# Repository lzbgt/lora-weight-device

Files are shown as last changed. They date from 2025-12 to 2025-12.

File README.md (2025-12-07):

# Hospital Urine Bag Monitoring System (LoRaWAN)

## Project Overview
A low-power, connected IoT device designed to automatically monitor urine output in hospital wards. It replaces manual visual checks with real-time digital logging, improving patient care and reducing nurse workload.

**Key Features:**
*   **Sensing:** Weight-based (Load Cell) for non-contact, universal bag compatibility.
*   **Connectivity:** **LoRaWAN** (Sub-1GHz) for deep indoor penetration and low infrastructure cost (1 gateway per ward).
*   **Battery Life:** Multi-year operation on AA batteries or Li-SoCl2.
*   **User Interface:** E-Ink Display for always-on visibility and local "Tare" button.
*   **Infrastructure:** Supports both **PoE** and **Wi-Fi** backhaul for the Gateway.

## Repository Structure

### Design Documents (`design_docs/`)
*   **`system_architecture.md`**: High-level topology, data flow, and server stack (ChirpStack).
*   **`hardware_design.md`**: Schematic concepts, chip selection (RAK3172, HX711), and detailed pin mapping.
*   **`mechanical_design.md`**: Enclosure styling, IP65 sealing, and the miniature load cell integration (Hook mechanism).
*   **`firmware_design.md`**: Software logic, state machine (Deep Sleep), and LoRaWAN payload format.
*   **`pcb_layout_guide.md`**: Critical routing rules for RF impedance and Analog noise reduction.
*   **`detailed_bom.md`**: Bill of Materials with part numbers and cost estimates.
*   **`solution_proposal.md`**: original proposal.

### Datasheets (`datasheets/`)
Contains reference specifications for critical components:
*   **RAK3172**: LoRaWAN Module.
*   **GDEY0213B74**: 2.13" E-Ink Display.
*   **HX711**: 24-Bit ADC.
*   **SSD1680**: Display Controller (Command Table).

## Getting Started

### 1. Hardware Development
*   Review `hardware_design.md` for the schematic connectivity.
*   Follow `pcb_layout_guide.md` for board layout, paying special attention to the **50Ω RF Trace** and **E-Ink Booster** loop.
*   Ensure the **Schottky Diode OR-ing** is implemented to protect the 3.3V rail.

### 2. Firmware Development
*   **Toolchain:** STM32CubeWL SDK + CMake + GCC ARM.
*   **Key Logic:** Implement the "Deep Sleep Loop" (Wait 400ms for HX711 -> Read -> Sleep).
*   **Display:** Use the SSD1680 driver with the specific bias voltages (+20V/-20V/+15V/-15V) defined in the hardware spec.

### 3. Mechanical Prototyping
*   Design the enclosure to fit the **Miniature Load Cell** (40mm).
*   Ensure the **Tube Retention Clip** is molded into the front shell to prevent measurement errors.

## License
Proprietary / Internal Company Use.

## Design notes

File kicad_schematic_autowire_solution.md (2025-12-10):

# KiCad schematic generation (no ERC) + “smart” auto‑wiring (obstacle‑avoiding)

This note assumes KiCad **6+** (`.kicad_sch` s‑expression format).

---

## 1) Generate schematics with *no ERC violations* (especially “unconnected pins”)

### 1.1 Treat ERC as a build step (don’t eyeball it)
Run ERC automatically after you generate/edit a schematic:

```bash
kicad-cli sch erc --format json --exit-code-violations path/to/root.kicad_sch
```

- `--exit-code-violations` lets you gate CI on a clean report.
- `--format json` makes it scriptable.  
(See KiCad CLI docs: https://docs.kicad.org/8.0/en/cli/cli.html)

You can also export a netlist for connectivity audits:

```bash
kicad-cli sch export netlist --format kicadsexpr path/to/root.kicad_sch
```

---

### 1.2 The three classic ERC pain points, and how to eliminate them

#### A) Pins that are intentionally unused → **add a no‑connect flag**
KiCad’s “no‑connection flags” explicitly tell ERC a pin is *intentionally* left open (and avoid “unconnected pin” violations).  
Docs explain the behavior and the stacked-pin corner case (no-connect breaks stacking connectivity):  
https://docs.kicad.org/6.0/en/eeschema/eeschema.html  
https://sources.debian.org/src/kicad/9.0.5%2Bdfsg-1~bpo13%2B1/doc/src/eeschema/eeschema_schematic_creation_and_editing.adoc

**File-format token:** the schematic file format defines:

```lisp
(no_connect (at X Y) (uuid <uuid>))
```

Source: KiCad developer file format docs: https://dev-docs.kicad.org/en/file-formats/sexpr-schematic/

**Script recipe**
1. Maintain an explicit “pin intent” list:
   - `CONNECTED` (must be in some net)
   - `NC` (must be intentionally unconnected)
2. For every `NC` pin, compute its absolute pin-end coordinate and emit a `no_connect` at that coordinate.
3. Re-run ERC; any remaining unconnected-pin issues are real mistakes.

> If a pin should *never* be connected in any schematic (true NC), set the **pin electrical type** to **Unconnected** in the *symbol library*. That also suppresses “unconnected pin” violations and prevents accidental wiring.

---

#### B) Power nets “not driven” → add **PWR_FLAG** (or a real power-output pin)
KiCad ERC often reports: **“Input Power pin not driven by any Output Power pins”** when power comes via connectors/batteries/etc. Add `PWR_FLAG` on those nets.

Docs:  
https://docs.kicad.org/6.0/en/eeschema/eeschema.html  
https://docs.kicad.org/8.0/en/getting_started_in_kicad/getting_started_in_kicad.pdf

**Script recipe**
- Identify nets with **power input** pins but **no power output** pins (via netlist export or ERC JSON).
- Place a `PWR_FLAG` symbol and wire it onto that net (or place the actual regulator output, etc.).

---

#### C) “It looks connected but ERC disagrees” → grid alignment & exact endpoints
KiCad connectivity is geometric: **wire endpoints must coincide** exactly with pin endpoints; wire crossings are not automatically connected.

Docs (grid + endpoint rule): https://docs.kicad.org/6.0/zh/eeschema/eeschema.html  
(“use a 50 mil grid”, and wires connect only when ends coincide)

**Script rule of thumb**
- Choose a grid (typically **50 mil = 1.27 mm**).
- Snap *every* generated coordinate to that grid.
- Ensure wires terminate **exactly** at pin ends (not “overlapping the symbol body”).

---

### 1.3 Minimal file-format snippets you’ll actually generate
Official s-expression format references:
- Schematic format: https://dev-docs.kicad.org/en/file-formats/sexpr-schematic/
- Common syntax (`pts`, `stroke`, units in **mm**): https://dev-docs.kicad.org/en/file-formats/sexpr-intro/index.html

**Wire**
```lisp
(wire
  (pts (xy X1 Y1) (xy X2 Y2) (xy X3 Y3))
  (stroke (width 0) (type default) (color 0 0 0 0))
  (uuid <uuid>)
)
```

**Junction** (use when you *intend* a connection at a 3+ segment intersection)
```lisp
(junction (at X Y) (diameter 0) (color 0 0 0 0) (uuid <uuid>))
```

**No-connect**
```lisp
(no_connect (at X Y) (uuid <uuid>))
```

---

## 2) Auto-wire pins “elegantly” (smart routing that avoids symbol bodies)

### 2.1 The big trick: separate *connectivity* from *ink*
In schematics, long wires are mostly UX debt. Net **labels** give correct connectivity without drawing a spaghetti bowl.

Docs: labels connect nets by name; you can connect without direct wire runs:  
https://docs.kicad.org/8.0/fr/eeschema/eeschema.html  (Labels section)

**Practical policy**
- **Local short connections** (inside a functional block): draw wires.
- **Global / long / high-fanout nets** (power, clocks, reset, buses, MCU GPIO groups): use *label stubs*.

That reduces the routing problem from “global autorouter” to “lots of tiny, clean stubs”.

---

### 2.2 Two-stage algorithm (what actually works in code)

#### Stage A — Placement (optional, but it’s where “smart” mostly lives)
No router can fully rescue bad placement. If you can, do a quick automatic placement pass:

- Build a graph: symbols = nodes, nets = hyperedges.
- Weight edges by:
  - number of pins on the net (fanout),
  - criticality (clock/reset), and/or
  - expected bus grouping (DATA[0..7]).
- Optimize a cost like:
  - total Manhattan distance of connected pins,
  - estimated crossings,
  - keep connectors on sheet edges, keep power at top/bottom, etc.

A force-directed layout or simulated annealing with grid snapping is usually “good enough”.

#### Stage B — Routing (orthogonal, obstacle-avoiding)
Model routing as grid-based Manhattan paths with obstacles.

**Geometry model**
- Coordinates: KiCad schematic s-expression uses **millimeters**.
- Use grid step: **1.27 mm** (50 mil) unless you have a reason not to.
- Obstacles:
  - symbol body bounding boxes (inflate by 1–2 grid steps as keepout),
  - optionally reference/value text boxes,
  - optionally existing wires as *soft* obstacles.

**Routing core**
- Use **A\*** on a 4-neighbor grid.
- Cost function (simple and effective):
  - `+1` per grid step (length)
  - `+BEND_PENALTY` when direction changes (minimize elbows)
  - `+CROSS_PENALTY` if you would cross an existing wire (prefer to detour)
  - `+NEAR_OBSTACLE_PENALTY` if too close to a symbol body (readability)
- Heuristic: Manhattan distance.

**Make it look human**
- After A\* returns a path (list of points), *compress* it:
  - remove collinear interior points so you emit 2–6 points, not 200.
- Use consistent posture:
  - default “horizontal then vertical” (or the reverse), and penalize “weird zigzags”.

---

### 2.3 Multi-pin nets: don’t route N² edges—build a trunk
For a net with many pins (e.g., `SPI_SCK` to 4 devices), you want a shared structure:

1. Compute a **hub** (Manhattan median):
   - `hub_x = median(pin_x)`, `hub_y = median(pin_y)`
2. Route each pin → hub (or pin → nearest point on a trunk line).
3. Merge overlapping segments.
4. Add junctions where branches meet.

This is a fast approximation to a rectilinear Steiner tree and works well visually.

**Even smarter heuristic**
- If pin points are mostly aligned horizontally, pick a **horizontal trunk** at `median(y)` and branch vertically.
- If mostly vertical, pick a vertical trunk.

---

### 2.4 Ultra-practical “elegant wiring” mode: stub + label
This is the cheat code for schematic legibility.

For each net:
- Place a label near each pin cluster.
- Draw a short orthogonal stub from pin end → label anchor.
- Don’t draw long inter-block wires at all.

You still get perfect connectivity and ERC cleanliness (as long as stub endpoints coincide with pin ends and label anchors are on the wire).

---

## 3) Skeleton Python approach (pseudo-code you can drop into a generator)

### 3.1 S-expression emitters (wire / junction / no_connect)
```python
from uuid import uuid4

def U(): return str(uuid4())

def sexpr_wire(points_mm):
    pts = " ".join(f"(xy {x:.3f} {y:.3f})" for x,y in points_mm)
    return f'(wire (pts {pts}) (stroke (width 0) (type default) (color 0 0 0 0)) (uuid {U()}))'

def sexpr_junction(x, y):
    return f'(junction (at {x:.3f} {y:.3f}) (diameter 0) (color 0 0 0 0) (uuid {U()}))'

def sexpr_no_connect(x, y):
    return f'(no_connect (at {x:.3f} {y:.3f}) (uuid {U()}))'
```

### 3.2 A* router (grid Manhattan, obstacle-avoiding) — minimal outline
```python
import heapq
from math import inf

DIRS = [(1,0),(-1,0),(0,1),(0,-1)]

def astar(start, goal, is_blocked, step=1):
    # start/goal are integer grid coords (gx, gy), not mm
    def h(a,b): return abs(a[0]-b[0]) + abs(a[1]-b[1])

    pq = [(h(start,goal), 0, start, None, None)]  # (f,g,node,parent,dir)
    best = {start: 0}
    parent = {}
    pdir = {}

    while pq:
        f,g,u,par,udir = heapq.heappop(pq)
        if u in parent:  # already expanded with best
            continue
        parent[u] = par
        pdir[u] = udir
        if u == goal:
            break

        for dx,dy in DIRS:
            v = (u[0]+dx, u[1]+dy)
            if is_blocked(v):
                continue
            bend = 0 if udir is None or udir==(dx,dy) else 5
            ng = g + 1 + bend
            if ng < best.get(v, inf):
                best[v] = ng
                heapq.heappush(pq, (ng + h(v,goal), ng, v, u, (dx,dy)))

    if goal not in parent:
        return None

    # reconstruct
    path = []
    cur = goal
    while cur is not None:
        path.append(cur)
        cur = parent[cur]
    path.reverse()
    return path
```

You’d wrap `is_blocked()` around:
- symbol keepouts,
- (optional) already-routed wires as soft blocks / high-cost regions,
- sheet boundaries.

Then convert grid coords → mm (`mm = grid * 1.27`) and compress collinear points.

---

## 4) A boring-but-realistic pipeline that works

1. Generate/update `.kicad_sch` (symbols + labels/wires).
2. Snap everything to grid; ensure wire endpoints coincide with pins.
3. Place `no_connect` on all intentionally unused pins.
4. Add `PWR_FLAG` where needed.
5. Run `kicad-cli sch erc --format json --exit-code-violations`.
6. Export SVG for visual diffing in CI (`kicad-cli sch export svg ...`).

When this passes reliably, you’ve basically built a schematic compiler.

---

## 5) Key references (official)
- Schematic file format (KiCad 6+): https://dev-docs.kicad.org/en/file-formats/sexpr-schematic/
- Common s-expression syntax (pts, stroke, **units in mm**): https://dev-docs.kicad.org/en/file-formats/sexpr-intro/index.html
- KiCad CLI (`kicad-cli sch erc`, netlist export): https://docs.kicad.org/8.0/en/cli/cli.html
- Eeschema docs (no-connect flag, PWR_FLAG, grid rules): https://docs.kicad.org/6.0/en/eeschema/eeschema.html

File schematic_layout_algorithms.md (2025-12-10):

# Schematic Auto-Layout Algorithms (KiCad `.kicad_sch` generator)

This document proposes **practical, implementable algorithms** to improve:
1) **Human readability (highest priority)**  
2) **Functional grouping / block coherence**  
3) **Space efficiency (only after 1 & 2 are satisfied)**  
4) **Automatic multi-page splitting (last resort)**

It is written to map cleanly onto your current Python-based KiCad schematic generator.

---

## 0) What the current generator does (and why it gets messy)

From `gen_urine_schematic.py`:

- **Placement**: instances are **hard-coded** in `INSTANCES = { ... (x,y) ... }` → no auto-placement.
- **Connectivity**: `emit_net()` draws **only a short stub from each pin and a net label** at the stub end.  
  There is **no actual multi-pin wiring / bus / junction topology**—the “connection” is purely by identical net labels.
- **Labeling**: label position is `at (stub_x, stub_y)` with a simple `justify` direction based on pin rotation.
  - There is **no collision detection** (label–label / label–symbol / label–wire).
  - High-fanout nets (GND/VCC/etc.) get **a label at every pin**, creating label density around dense ICs.

That combination is fast to generate, but it tends to produce **label clouds** near chips with many pins (MCU/module, large connectors), and it does not visually communicate circuit structure (only names).

---

## 1) Model the problem explicitly

Represent the schematic as **objects** with geometry and constraints:

### 1.1 Objects
- **Symbol instance** `S`: position `(x,y)`, orientation `rot`, bounding box `bbox(S)`
- **Pin** `p`: absolute anchor point `(x_p,y_p)`, preferred stub direction `dir(p)`
- **Net** `n`: a hyperedge connecting pins `P(n) = {p1, p2, ...}`
- **Wire segment** `w`: orthogonal polyline with clearance
- **Label** `L`: rectangle `bbox(L)` with anchor `(x_a,y_a)` and chosen candidate `(x,y,justify)`

### 1.2 Constraints (hard)
- No symbol overlap (bbox separation ≥ margin).
- Wires do not pass through symbols (treat symbol bbox inflated by clearance as obstacle).
- Label boxes do not overlap symbols; label–label overlaps should be minimized, ideally eliminated.
- Grid snapping.

### 1.3 Objectives (soft, prioritized)
1. **Readability**
   - minimize label overlaps, wire crossings, wire bends, “untraceable” hops
   - align and simplify (straight lines, consistent directions)
2. **Functional grouping**
   - strongly-related components should be near each other and visually “boxed”
3. **Space**
   - reduce page area only after readability/grouping are good enough
4. **Split to pages**
   - only if constraints cannot be met on one page

A key implementation detail: use a **lexicographic / tiered optimizer**:
- First minimize *readability cost*;
- subject to that, minimize *grouping cost*;
- subject to both, minimize *area*.

This prevents the “packed but unreadable” failure mode.

---

## 2) Recommended pipeline (works for small and large schematics)

1. **Preprocess nets**
   - Identify *global nets* (power/ground/high-fanout) and remove them from clustering.
2. **Functional grouping (clustering / partitioning)**
   - Assign components into blocks: Power, MCU, Sensors, Display, UI, Connectors, etc.
3. **Block-level placement (macro layout)**
   - Place block rectangles on page with a clear flow (left→right, top→bottom).
4. **Within-block placement (micro layout)**
   - Place the anchor IC/connector; attach passives around relevant pins; enforce conventions.
5. **Routing strategy**
   - Draw explicit wires for *local nets*; use labels/buses/harnesses for long or inter-block nets.
6. **Label placement (collision-aware)**
   - Choose label positions from candidates via greedy + local repair (or ILP if you want).
7. **Compaction (gentle whitespace reduction)**
   - Tighten only where it does not harm readability.
8. **If it still doesn’t fit → multi-page split**
   - Partition blocks into pages minimizing inter-page nets.

---

## 3) Step 1: Net preprocessing / classification

### 3.1 Detect nets that should NOT drive grouping
These nets connect almost everything and destroy clustering:
- `GND`, `VCC`, `VBUS`, `BAT`, `3V3`, `5V`, etc.
- Any net with degree ≥ `fanout_global` (e.g., ≥ 8 pins)

**Algorithm:**
```
global_nets = { n | degree(n) >= fanout_global } ∪ { n | name matches power_regex }
```

### 3.2 Net types drive drawing style
Classify nets into:
- **Global**: power rails, ground, high-fanout  
  → use *power symbols* or *one label per block*, not per-pin labels.
- **Local**: connects pins within same block and small degree (≤ 3)  
  → draw explicit wires (pattern routing).
- **Inter-block**: connects pins across blocks  
  → use ports + labels, or bus/harness if many nets cross between same two blocks.

---

## 4) Step 2: Functional grouping (block extraction)

### 4.1 Build a weighted component graph from the hypergraph
Construct a graph `G=(V,E)` where each component is a node. For each net `n` (excluding global nets):
- For all pairs of components `(u,v)` connected by `n`, add edge weight:
  - **Option A (simple):** `w += 1`
  - **Option B (better):** `w += 1/(degree(n)-1)`  
    (downweights medium-fanout nets so they don’t glue everything together)

Also add heuristics:
- Boost weights for “tight” relationships:
  - decoupling caps to IC VDD pins
  - crystal + load caps to MCU
  - regulator + inductor + diode + feedback resistors

You can infer these by net names (`VDD`, `VCC`, `FB`, `SW`, `XI/XO`) and component types.

### 4.2 Two practical clustering strategies

#### Strategy A: Anchor-based assignment (very practical)
1. Identify **anchors**: ICs/modules/connectors/regulators (high pin count or known library class).
2. Assign passives to nearest anchor by graph distance:
   - compute shortest-path distance in `G` from passive to each anchor
   - assign to the closest; tie-break by sum of incident edge weights

This produces blocks that match human intuition.

#### Strategy B: Community detection / partitioning (more general)
Run Louvain/Leiden (modularity) or spectral clustering on `G`.  
Then optionally label clusters by anchor types (power cluster, MCU cluster, etc.).

**Good hybrid**: Strategy A for passives + Strategy B to merge/split anchor clusters.

### 4.3 Block constraints you should enforce
- Minimum/maximum block size (component count) to avoid tiny or huge blocks.
- “Keep together” rules:
  - parts sharing a local analog reference should not be split
- “Separate” rules:
  - noisy power switching block should be spatially separated from sensitive analog block

---

## 5) Step 3: Block-level placement (macro layout)

### 5.1 Build the block graph
Nodes = blocks; edge weight = number of inter-block nets (excluding globals), or sum of net weights.

### 5.2 Place blocks with readable flow
A robust heuristic layout (works well for schematics):

1. Pick a **central block** (often MCU/module) as root.
2. Categorize blocks:
   - Power (sources/rails)
   - IO/connectors (edges)
   - Sensors/analog (near MCU but separated from switching power)
   - Display/UI (near MCU, usually right side)
3. Use a **constrained force model** on block rectangles:
   - attraction ∝ inter-block edge weight
   - repulsion to avoid overlap
   - soft constraints:
     - Power blocks prefer bottom-left / left
     - Connectors prefer page edges
     - UI/display prefer right/top-right
4. Snap block origins to grid.

This gives a good first macro layout.

### 5.3 Convert to a clean orthogonal macro arrangement (optional but recommended)
After force placement, apply **orthogonalization / rectilinear cleanup**:
- enforce a small set of canonical x-columns and y-rows for blocks
- align blocks to form clean “lanes” for buses

This increases readability more than it costs area.

---

## 6) Step 4: Within-block placement (micro layout)

### 6.1 Anchor-first placement
For each block:
1. Place the **anchor** (main IC/connector) at the block center.
2. Choose anchor **orientation** to minimize wire/label conflicts:
   - place high-traffic nets on left/right sides according to flow
   - keep power pins on top (if symbol supports that convention), ground bottom

Orientation selection can be done by minimizing:
```
rot_cost = Σ_n traffic(n) * projected_distance(pin_side(rot,n), preferred_side(n))
```

### 6.2 Attach passives near the pins they serve
For each passive `c` in block:
- Determine its **attachment pin(s)**:
  - For 2-pin passive: attach to the *more specific* net end (not GND/VCC)
  - For decoupling cap: attach to the IC VDD pin
- Compute target point = anchor pin position + outward offset.
- Place passives on a “ring” around anchor, grouped by side (left/right/top/bottom).
- Sort by the anchor pin y-order (for left/right sides) to reduce crossings.

This mimics how humans draw: passives line up alongside the pins they connect to.

### 6.3 Collision resolution (simple but effective)
After initial placement:
- Run a discrete “push-out” pass:
  - detect overlaps between symbol bboxes
  - for each overlap pair, move the lighter/smaller part outward along the nearest free direction
  - re-snap to grid
Repeat for a few iterations.

---

## 7) Step 5: Wiring strategy (make the topology legible)

### 7.1 Don’t label everything
Your current “stub+label for every pin” is the biggest readability killer.

Instead:
- **Global nets**: power symbols or one label per local rail, not per pin.
- **Local nets** (within a block): draw real wires (short, orthogonal).
- **Inter-block nets**: labels/ports; group many nets as buses.

### 7.2 Local-net orthogonal routing (pattern first, maze fallback)
For a connection between two pins A and B:

1. Try **I-route** (straight) if aligned and unobstructed.
2. Else try **L-route** (one bend) with two candidate elbows:
   - `(xA, yB)` and `(xB, yA)` if unobstructed.
3. Else try **Z-route** (two bends) using a small set of channel y-levels or x-levels.
4. Else run a lightweight **grid A*** router:
   - nodes on GRID
   - obstacles = inflated symbol bboxes + existing wires
   - cost = length + bend_penalty + near_wire_penalty

This keeps most wiring clean without heavy computation.

### 7.3 High-degree nets inside a block: use a local bus spine
If a net connects to many pins in the same block (but you don’t want global):
- create a **spine** (a horizontal or vertical trunk line)
- connect each pin to the spine with short orthogonal branches
- put **one net label** on the spine

This reduces label duplication dramatically and improves traceability.

---

## 8) Step 6: Label placement (collision-aware, practical)

Label placement is a classic “annotate anchors without collisions” problem.

### 8.1 Generate candidate label positions per anchor
For each label with anchor point `(x_a, y_a)` and a preferred direction `dir`:
- create candidates at increasing distance along `dir`: `d ∈ {0, 1, 2} * GRID`
- for each, create perpendicular nudges `p ∈ {-1, 0, +1} * GRID`
- include a “flip side” candidate if all else fails

For horizontal stubs, candidates are typically:
- right/left with above/below nudges

For vertical stubs:
- top/bottom with left/right nudges

### 8.2 Approximate text box size (good enough for collision tests)
If KiCad font size is `h` (e.g., 1.27mm), approximate:
- `char_w ≈ 0.6*h`
- `w = char_w * len(text)`
- `bbox = (x, y, x+w, y+h)` adjusted by justification

This is sufficient to avoid obvious overlaps.

### 8.3 Cost function (readability-first)
For each candidate `c` for label `i`:
```
cost(c) =
  W_overlap * (overlap_area_with_symbols + overlap_area_with_labels)
+ W_wire    * crossings_or_close_proximity_to_wires
+ W_dist    * distance(anchor, label)
+ W_edge    * outside_page_penalty
+ W_style   * (breaks_consistency_penalty)
```

Make `W_overlap` dominant.

### 8.4 Solver options

#### Option A (fast): Greedy + repair
1. Sort labels by congestion:
   - longer names first, then anchors in dense regions
2. Place each label at lowest cost candidate given already placed.
3. Repair pass: for remaining overlaps, push labels outward along least-colliding direction.

This handles 95% of cases.

#### Option B (strong): ILP for per-block label placement
Binary variable `x_{i,c}` = 1 if label i chooses candidate c.

Constraints:
- each label chooses exactly one candidate
- no overlap constraints for pairs that overlap (precompute conflict graph)

Objective:
- minimize Σ x_{i,c} * cost_{i,c}

This gives near-optimal label placement per block (typically small enough to solve quickly).

---

## 9) Step 7: Gentle compaction (space efficiency without hurting readability)

Once blocks, symbols, wires, labels are placed and collision-free:
- perform **compaction** to remove large unused gaps while preserving constraints.

### 9.1 Constraint-graph compaction (robust)
Build constraints:
- If object A must be left of B (because they overlap in y-range), add:
  `x_B ≥ x_A + width(A) + margin`
- Similar for vertical.

Solve by longest-path in a DAG (if you maintain a consistent ordering), or by iterative relaxation.

### 9.2 Heuristic “sweep” compaction (easy)
Repeat a few times:
- left-sweep: move each object left until it would violate any constraint
- top-sweep: move up similarly
- snap to grid

Stop when improvement is small.

Important: do compaction **after** label routing, otherwise you’ll reintroduce collisions.

---

## 10) Step 8: Multi-page splitting (last resort)

Only do this if:
- after grouping + placement + compaction, the layout cannot fit page bounds **without violating readability constraints**, or
- label density exceeds a threshold in one region even after rerouting.

### 10.1 Partition blocks into pages (min-cut with capacity)
Treat blocks as items with “area” (estimated block bbox) and “complexity” (component count, label count).  
Partition the block graph to minimize cut edges (inter-page nets), subject to:
- page area capacity
- max complexity per page

Practical algorithm:
- Start with one page; place largest/central block (MCU) first.
- Iteratively add neighboring blocks that:
  - fit capacity
  - add minimal new cut weight
- When no block fits, start a new page.
- Optionally run a KL/FM refinement pass to swap blocks between pages and reduce cuts.

### 10.2 Represent inter-page connectivity cleanly
- For a few nets: use **sheet ports** (hierarchical labels) or off-page connectors.
- For many nets between same two pages: create a **bus/harness**:
  - bus label like `EINK[CS,RST,DC,BUSY,SCK,MOSI]`
  - keep per-signal labels near endpoints, but route as a single bus trunk

### 10.3 Add a top-level overview page (recommended)
Generate a page 0:
- one block symbol per sheet
- buses between sheets
- power distribution

This massively improves human readability for multi-page designs.

---

## 11) How this maps back to your Python generator

### 11.1 Replace hard-coded `INSTANCES` positions
- Compute blocks and placements; assign `(x,y)` per instance from the algorithm.
- Keep your symbol parsing; add:
  - symbol bbox estimation
  - orientation (`rot`) selection support

### 11.2 Stop emitting one label per pin for global/high-degree nets
- Emit KiCad **power symbols** where possible.
- Or emit exactly one label per block spine and connect to it.

### 11.3 Add a label-placement module
- Maintain label objects; generate candidates; compute bbox overlaps; choose candidates.

### 11.4 Optional: generate actual wires for local nets
- Implement pattern routing; fallback to A* in a grid with obstacles.

---

## 12) Metrics & regression tests (so improvements are measurable)

Track:
- number of label–label overlaps (should be 0)
- number of label–symbol overlaps (must be 0)
- wire crossings (minimize)
- average pin-to-label distance (small)
- pages used (minimize *after* readability)
- block cut weight (minimize)

Create a golden-image regression:
- render PDF from KiCad and compare to baseline with perceptual diff (optional).

---

## 13) Practical defaults (good starting values)

- `GRID = 1.27mm`
- `fanout_global = 8`
- label candidate distances: `{0, 1, 2} * GRID`
- minimum symbol spacing: `2 * GRID`
- dominant label overlap weight: `W_overlap = 1000`
- wire bend penalty: `bend_penalty = 2*GRID` (in A* cost units)

---

### TL;DR
The biggest wins come from:
1) **Cluster into blocks** (ignore global nets for clustering)  
2) **Draw real wires inside blocks** and **use fewer labels** (spines/buses/global rails)  
3) **Collision-aware label placement** (candidates + greedy/ILP)  
4) **Only then** compact and split pages if truly necessary

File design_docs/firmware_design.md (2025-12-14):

# Firmware Design & Specification

## 1. Architecture: Professional SDK (CMake/STM32Cube)
The firmware will be developed as a standard C/C++ project using the **STM32CubeWL MCU Package** and built via **CMake**. This approach allows full control over the Sub-GHz radio stack, low-power modes, and memory layout.

### Toolchain & Environment
*   **Compiler:** `arm-none-eabi-gcc` (Latest stable).
*   **Build System:** **CMake** + **Ninja** / **Make**.
*   **SDK:** **STM32CubeWL Firmware Package** (HAL + LL Drivers).
*   **LoRaWAN Stack:** **LoRaMac-node** (Reference implementation from Semtech/ST) integrated within STM32Cube.
*   **IDE (Optional):** VS Code (with CMake Tools extension) or STM32CubeIDE (headless build support).

### Project Structure
```text
/firmware
├── CMakeLists.txt          # Main build script
├── Drivers/                # STM32 HAL/LL, CMSIS
├── Middlewares/            # LoRaWAN Stack, FreeRTOS (optional)
├── Core/
│   ├── Inc/                # Application Headers
│   └── Src/                # Application Source
│       ├── main.c          # Entry point & System Clock
│       ├── app_lorawan.c   # LoRaWAN Task/Callbacks
│       ├── hx711_driver.c  # Bit-banged or SPI-based driver
│       └── epd_driver.c    # SSD1680 E-Ink Driver
```

## 1.1 Development & Flashing Interface (USB‑C)
Hardware provides:
- **USB power** on `VBUS`
- **USB bridge MCU (STM32F042F6P6)** that exposes **USB CDC (UART2_TX/UART2_RX)** and **CMSIS‑DAP SWD** over the same cable.
- **Primary dev path:** single USB‑C into the on‑board STM32 bridge (3.3 V). SWD is wired to the target pogo pads and to the bridge so you can use either the on‑board CMSIS‑DAP or an external probe.

Recommended firmware/development flow:
- **Console:** enable `USART2` and route `printf`/logs to UART2.
- **Flashing:** use either (a) STM32 ROM bootloader over the USB CDC path (assert `BOOT0` + reset) or (b) SWD via the on‑board CMSIS‑DAP bridge.
  - `BOOT0=1` + reset → ROM bootloader on UART
  - `BOOT0=0` + reset → normal firmware

## 2. Operating Logic (State Machine)
To ensure <2uA sleep current, the application will use the **STM32 Low Power Manager (LPM)** utility or a custom `EnterStopMode` routine.

### Main Loop (Bare Metal or RTOS)
Given the simplicity, a **Super-Loop with Interrupts** or a light **FreeRTOS** implementation is suitable. The logic follows:

1.  **Bootloader:** Verify system integrity, jump to App.
2.  **System Init:**
    *   Clock: MSI Range 11 (48MHz) for active, LSE (32.768kHz) for RTC/LoRa.
    *   GPIO: Set all unused pins to Analog mode (High-Z) to save power.
    *   ADC: Calibrate VREFINT.
    *   Display: Init SPI, Clear screen (White), Show Logo, then Deep Sleep Display.
3.  **LoRaWAN Join:**
    *   Load Keys from Flash/EEPROM.
    *   Send Join Request (OTAA).
    *   Wait for Join Accept.
4.  **Deep Sleep Loop:**
    *   **RTC Alarm** wakes MCU every 60 seconds.
    *   **Wakeup Action:**
        *   Enable Power Gate (`PB5` LOW).
        *   **Wait 400ms** (HX711 Output Settling Time @ 10SPS, ref: **Datasheet Table 2, Note 1**).
        *   Read HX711 (Bit-bang `PB6`/`PA15` or Hardware SPI).
        *   Disable Power Gate (`PB5` HIGH).
        *   **CRITICAL:** Set `PB6` (SCK) Low/Analog.
        *   Measure Battery (ADC `PB4`).
    *   **Logic:**
        *   **Button Event (Interrupt):**
            *   **Short Press (< 2s):** Tare (Zero current weight).
            *   **Long Press (> 2s):** Toggle Measurement Mode (Standard 2000mL <-> Extended 8.5kg).
            *   *Note:* Extended range is hardware-limited to ~8.5kg due to HX711 Gain 32 saturation at 3.3V excitation.
        *   **Artifact Rejection:**
            *   Compare `Current_Weight` vs `Previous_Weight`.
            *   If delta > `MAX_FLOW_PER_MIN` (e.g., 50ml) AND not a "Reset/Empty" event:
            *   Ignore reading (assume tube pull/bed shake).
            *   Schedule rapid re-check (e.g., in 10 seconds).
        *   Delta check: Has weight changed > 50g (Stable)? -> Update Display.
        *   Alarm check: Weight > Threshold? -> Buzzer PWM (`PA8`) + Uplink.

## 4. Pseudocode (RUI3 Style)

```cpp
#include "RAK3172_RUI3.h"

// Settings
#define REPORT_INTERVAL (60 * 60 * 1000) // 1 hour
#define ALARM_THRESHOLD_ML 1800         // 80% of 2L bag

// Pin Definitions (Match Hardware Design)
#define PIN_POWER_GATE  PB5             // P-MOSFET (Low=ON, High=OFF)
#define PIN_BUZZER      PA8             // PWM
#define PIN_HX711_SCK   PB6
#define PIN_HX711_DT    PA15            // Data
#define PIN_EINK_BUSY   PA0             // Input
#define PIN_EINK_CS     PA4
#define PIN_EINK_DC     PA1
#define PIN_EINK_RST    PB12
#define PIN_BUTTON      PB3

// HX711 Config
// FX1901 Sensitivity = 20mV/V. Full Scale V_out = 66mV (at 3.3V).
// Gain 32 Range = +/- 51.5mV.
// Max Measurable Weight = (51.5 / 66) * 11kg = ~8.5kg.

// Global Flags
volatile bool evt_tare = false;
volatile bool evt_toggle_mode = false;
volatile uint32_t press_start_time = 0;

// Global Data
int32_t tare_offset = 0;
bool display_is_kg = false; // Default: mL (approx g)

void setup() {
    // ... Init code ...
    pinMode(PIN_BUTTON, INPUT_PULLUP);
    attachInterrupt(PIN_BUTTON, buttonPressHandler, FALLING);
    attachInterrupt(PIN_BUTTON, buttonReleaseHandler, RISING);
}

void buttonPressHandler() {
    press_start_time = millis();
}

void buttonReleaseHandler() {
    uint32_t duration = millis() - press_start_time;
    // Debounce: Ignore presses < 50ms
    if (duration > 50 && duration < 2000) {
        evt_tare = true;
    } else if (duration >= 2000) {
        evt_toggle_mode = true;
    }
}

void wakeUpHandler(void *data) {
    // 1. Power Up Sensor
    digitalWrite(PIN_POWER_GATE, LOW);
    // Wait 400ms (HX711 Output Settling Time @ 10SPS, ref: Datasheet Table 2, Note 1)
    delay(400); 
    
    // 2. Read Sensor (Channel B - Gain 32)
    // WARNING: FX1901 Full Scale (11kg) Output (66mV) > HX711 Range (51.5mV).
    // Sensor will SATURATE at > 8.5kg.
    int32_t raw_reading = readHX711_ChannelB();
    
    // 3. Power Down
    digitalWrite(PIN_POWER_GATE, HIGH);
    digitalWrite(PIN_HX711_SCK, LOW);

    // 4. Handle Input
    if (evt_tare) {
        tare_offset = raw_reading;
        evt_tare = false;
        // Refresh display to show 0
        updateDisplay(0, display_is_kg);
    }
    
    if (evt_toggle_mode) {
        display_is_kg = !display_is_kg;
        evt_toggle_mode = false;
        // Force update to show new unit icon
        float weight = (raw_reading - tare_offset) * CALIBRATION_FACTOR;
        updateDisplay(weight, display_is_kg);
    }

    // 5. Process Weight
    currentWeight = (raw_reading - tare_offset) * CALIBRATION_FACTOR;
    
    // ... Logic ...
}

void updateDisplay(float val, bool is_kg) {
    // Driver code to update E-Ink with value and "mL" or "kg" icon...
}
```

## 3. Key Driver Implementation Details

### A. E-Ink (SSD1680)
*   **Driver:** Port the GoodDisplay/Waveshare C routines to STM32 HAL SPI.
*   **Optimization:** Use **Partial Refresh** for volume updates (faster, less flickering) and **Full Refresh** only once every 6 hours to clear ghosting.
*   **Power:** Ensure the display is put into "Deep Sleep Mode" (command `0x10`, data `0x01`) before the MCU sleeps.

### B. HX711 (Load Cell)
*   **Config:** **Gain 32 (Channel B)**.
    *   **Gain Calculation:**
        *   **Sensor:** FX1901 (20mV/V). Excitation 3.3V. Full Scale Output = 66mV (at 11kg/25lb).
        *   **HX711 Range (Gain 32, 3.3V):** $\pm 0.5 \times (3.3V / 32) = \pm 51.5mV$.
        *   **Analysis:** The sensor's full 11kg output (66mV) technically exceeds the ADC range (51.5mV).
        *   **Application Reality:** Max urine bag weight is ~2kg (2000mL).
        *   **Operating Point:** At 2kg, signal is approx $66mV \times (2kg / 11kg) \approx 12mV$.
        *   **Conclusion:** Gain 32 provides **best resolution** for the primary 0-2kg target. Saturation at >8.5kg is a known trade-off.
        *   *Mitigation:* If >8.5kg measurement is required, firmware must switch to Gain 64 (Channel A) or hardware must reduce excitation voltage.
*   Since the RAK3172 is fast (48MHz), bit-banging the 24-bit readout requires delays to match the HX711 timing (max 400kHz SCK).
*   **GPIO Initialization:** All GPIO pins associated with the HX711 driver (SCK, DT) must be initialized using standard HAL enumerations (e.g., `GPIO_MODE_OUTPUT_PP`, `GPIO_NOPULL`) to ensure correct and robust pin configuration.
*   **Conversion:** `Weight_g = (Raw_Value - Tare_Offset) / Calibration_Factor`.

### C. LoRaWAN (LoRaMac-node)
*   **Region:** `LORAMAC_REGION_US915` or `LORAMAC_REGION_EU868` (defined in CMake).
*   **Class:** Class A.
*   **ADR:** Enabled (Adaptive Data Rate) to save power if close to gateway.

### D. Calibration Strategy (Dual-Slope)
To ensure maximum accuracy in the primary application range (0-2000mL) while supporting extended loads:
1.  **Zone 1 (0 - 2000g):** Calibrated with a 2kg master weight. This slope is optimized for the linear region of the sensor where urine volume matters most.
2.  **Zone 2 (2000g - 8500g):** A secondary correction factor is applied to handle potential non-linearity or droop in the sensor response at higher loads.

## 4. Payload Format (Packed)
*Same as previous design, consistent with CayenneLPP or Custom.*

| Byte | Function | Range / Value |
| :--- | :--- | :--- |
| **0** | Status Flags | Bit 0: Low Batt, Bit 1: Full Alarm, Bit 2: Blockage |
| **1** | Battery % | 0-100 (derived from V_measure vs V_full) |
| **2-3** | Volume (mL) | uint16_t (Little Endian) |
| **4-5** | Flow (mL/h) | uint16_t (Little Endian) |

## 5. CMakeLists.txt Snippet
```cmake
cmake_minimum_required(VERSION 3.16)
project(UrineMonitor C CXX)

set(CMAKE_C_STANDARD 11)
set(MCU_FLAGS "-mcpu=cortex-m4 -mthumb -mfpu=fpv4-sp-d16 -mfloat-abi=hard")

add_definitions(-DUSE_HAL_DRIVER -DSTM32WLE5xx)

# Include STM32CubeWL Sources
file(GLOB_RECURSE HAL_SOURCES "Drivers/STM32WLxx_HAL_Driver/Src/*.c")
file(GLOB_RECURSE LORA_SOURCES "Middlewares/Third_Party/LoRaWAN/LrMac/*.c")

add_executable(${PROJECT_NAME}.elf 
    Core/Src/main.c
    Core/Src/system_stm32wlxx.c
    ${HAL_SOURCES}
    ${LORA_SOURCES}
)

target_compile_options(${PROJECT_NAME}.elf PRIVATE ${MCU_FLAGS} -Wall -Os)
target_link_options(${PROJECT_NAME}.elf PRIVATE ${MCU_FLAGS} -T${CMAKE_SOURCE_DIR}/STM32WLE5CCUx_FLASH.ld -Wl,--gc-sections)
```

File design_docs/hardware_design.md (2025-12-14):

# Hardware Design (Current Plan)

This document is the *current* hardware plan used by the programmatic KiCad generators in `tools/`. It replaces earlier drafts that assumed a PCB‑mounted AA holder and large debug headers.

## Recent schematic/PCB updates
- **USB-C is now the single development connector**: full USB2 D+/D- feed an on‑board STM32F042 acting as USB CDC (UART) + CMSIS‑DAP SWD.
- **CH340C removed; STM32F042F6P6 replaces it** to provide both UART console and SWD/JTAG‑style debug over the same cable (3.3 V powered, with local decoupling).
- **Field power is via a 2‑wire JST‑PH** feeding the TPS61220 boost and Schottky OR-ing with the USB LDO.

## 1. System Role
- **Device:** LoRaWAN Class‑A end node
- **Connectivity:** Sub‑1 GHz LoRa (RAK3172 module)
- **UI:** 2.13" e‑paper (SSD1680) connected by FPC cable; local button + buzzer + status LED
- **Power:** USB‑C for development power; external battery pack for field deployment (2‑wire JST)

## 2. External Interfaces (Connectors)
- **USB‑C (Dev)**: single connector for development **power + console + flashing**
  - Power: `VBUS` (5 V) into an LDO → 3.3 V
  - Data: USB2 D+/D‑ into **STM32F042F6P6** (USB CDC + CMSIS‑DAP SWD)
  - Flashing: via STM32 UART bootloader over the USB CDC path (requires `BOOT0` + reset access; see `design_docs/firmware_design.md`)
  - SWD/JTAG: kept as **optional** pogo‑pad footprint (preferred) rather than a large 2.54 mm header
- **Battery (Field)**: 2‑wire JST‑PH (`BAT`, `GND`) to an external battery case/pack
- **Load Cell**: 4‑wire header (`E+`, `E-`, `A+`, `A-`) into HX711
- **Display**: 24‑pin 0.5 mm FPC connector for the GDEY0213B74 flex cable
- **Antenna**: u.FL/I‑PEX RF connector near the RAK3172 RF pin (short 50 Ω trace)

## 3. Key Silicon & Roles
### A. MCU + RF: RAK3172 (STM32WLE5)
- Integrated LoRa radio; certified module reduces RF risk.

### B. Load cell ADC: HX711 (SOIC‑16)
- 24‑bit ADC with PGA; reads strain gauge bridge.
- `HX_VCC` is **power‑gated** during sleep to eliminate bridge + HX711 draw.

### C. Power
- **Battery boost (field):** TI **TPS61220** (wide VIN, 3.3 V rail generation).
- **USB LDO (dev power):** Microchip **MIC5504‑3.3** from `VBUS` → 3.3 V.
- **Power ORing:** Schottky diodes into the system rail `VCC` (one from battery boost, one from USB LDO).
- **Battery sense:** 1 MΩ / 1 MΩ divider from `BAT` to ADC (`BAT_SENSE`) so firmware can report battery health even when on USB power.

### D. USB Console + Debug Bridge
- **STM32F042F6P6** provides USB CDC (console/logs, UART bootloader access) and CMSIS‑DAP SWD over the same USB‑C connector. Target SWDIO/SWCLK/NRST and UART2 RX/TX are wired to this bridge and also brought out to the pogo/debug header.

## 4. Pin Mapping (Summary)
### A. RAK3172 → System
| RAK3172 Pin | Net | Function | Notes |
|---:|---|---|---|
| 1 | `UART2_RX` | console RX | From USB bridge (STM32F042) TXD |
| 2 | `UART2_TX` | console TX | To USB bridge (STM32F042) RXD |
| 3 | `HX711_DT` | HX711 data | `PA15` |
| 4 | `HX711_SCK` | HX711 clock | `PB6` (must be LOW before gating) |
| 6 | `EINK_DC` | E‑ink D/C | `PA1` |
| 7 | `SWDIO` | SWD IO | optional pogo pads |
| 8 | `SWCLK` | SWD CLK | optional pogo pads |
| 9 | `I2C_SCL` | I2C | expansion |
| 10 | `I2C_SDA` | I2C | expansion |
| 13 | `EINK_MOSI` | SPI MOSI | `PA7` |
| 15 | `EINK_SCK` | SPI SCK | `PA5` |
| 16 | `EINK_CS` | SPI CS | `PA4` |
| 19 | `BUZZ_PWM` | buzzer PWM | `PA8` |
| 26 | `LED_STATUS` | status LED | `PB2` |
| 27 | `EINK_RST` | e‑ink reset | `PB12` |
| 29 | `EINK_BUSY` | e‑ink busy | `PA0` |
| 30 | `HX_GATE` | HX gate | drives SI2301 |
| 31 | `BAT_SENSE` | battery ADC | divider from `BAT` |
| 32 | `BTN_USER` | button | active‑low |

### B. STM32F042F6 (USB Bridge) → System
| STM32F042 Pin | Net | Function | Notes |
|---:|---|---|---|
| 16 / VDDA | `VCC` | 3.3 V | shared decoupling with C4 |
| 15 / VSSA | `GND` | ground | analog/digital common |
| 17 / PA11 | `USB_DM` | USB D– | to J3 |
| 18 / PA12 | `USB_DP` | USB D+ | to J3 |
| 19 / PA13 | `SWDIO` | target SWDIO | feeds RAK3172 / pogo |
| 20 / PA14 | `SWCLK` | target SWCLK | feeds RAK3172 / pogo |
| 14 / PB1  | `NRST`  | target reset | drives module reset |
| 8  / PA2  | `UART2_RX` | UART TX to RAK | bridge → target |
| 9  / PA3  | `UART2_TX` | UART RX from RAK | target → bridge |
| 4  / NRST | `NRST` | MCU reset | pulled up, brought to USB-C reset strap |

### C. Connectors (External)
| Ref | Pins | Nets | Purpose |
|---|---|---|---|
| J3 | USB‑C | `VBUS`, `USB_DP`, `USB_DM`, `CC1`, `CC2`, `GND` | Dev power + CDC + CMSIS‑DAP |
| J1 | 1x4 | `E+`, `E-`, `A+`, `A-` | Load cell |
| J2 | 24‑pin FPC | SPI + HV rails | E‑ink flex |
| J4 | 1x05 | `GND`, `VCC`, `I2C_SCL`, `I2C_SDA`, `BOOT0` | Minimal breakout |
| J5 | u.FL | RF feed | Antenna |
| BT1 | JST‑PH‑2 | `BAT`, `GND` | Battery input |

## 5. E‑Ink Display Notes (GDEY0213B74 / SSD1680)
- The PCB hosts only the **24‑pin FPC connector**; the display module mounts elsewhere in the enclosure and connects via the flex cable.
- SPI interface uses `BUSY/RES#/D/C#/CS#/SCL/SDA` and `BS1` strapped for 4‑wire SPI.
- The SSD1680 requires an **external booster/regulator application circuit** (inductor + MOSFET + Schottky diodes + capacitors) for the HV rails. Reference:
  - `datasheets/GDEY0213B74.pdf` (module reference circuit)
  - `datasheets/SSD1680.pdf` (Section 6.3 “Booster & Regulator”)
- Layout requirements (important):
  - Place the HV booster parts and HV capacitors **right next to the FPC connector**.
  - Keep the switching loop (L + MOSFET + diodes) **extremely small**.
  - Keep the HV area away from HX711 analog inputs and away from the RF feed.

## 6. PCB Placement Priorities (Professional Layout)
- **USB edge:** USB‑C centered on a short edge; STM32F042 bridge + LDO close to it; keep copper for heat spreading.
- **Analog corner:** Load cell connector + HX711 + its decoupling close together; keep noisy switching/HV away.
- **RF edge:** RAK3172 near top edge with u.FL near RF pin; short 50 Ω feed; ground stitching.
- **Display edge:** FPC connector on board edge to simplify cable routing; HV caps clustered next to pins.
- **Silkscreen:** keep `U* / R* / C* / J*` reference designators visible on `F.SilkS` (assembly‑friendly).

## 7. Known Issues / TODO
- Implement the SSD1680/GDEY0213B74 HV booster circuit in the schematic generator (currently some HV pins are stubbed as NC).
- Ensure `BAT_SENSE` measures the battery input (`BAT`) and not the post-OR system rail (`VCC`).

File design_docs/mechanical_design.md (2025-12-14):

# Mechanical & Enclosure Design

## 1. Design Requirements
*   **Environment:** Clinical Hospital Ward (Clean, but potential splashes).
*   **Rating:** **IP65** (Dust tight + Water jets). Essential for cleaning/disinfection.
*   **Mounting:** Must attach securely to standard Hospital Bed Rails (0.8" - 1.5" diameter) or hang from the bed frame.
*   **Load Interface:** Must securely hold a 2000mL (approx 2kg) urine bag.

## 2. Enclosure Concept (The "Shell")
*   **Material:** **ASA (Acrylonitrile Styrene Acrylate)** or **PC-ABS**.
    *   *Why:* UV stable (won't yellow under hospital lights), chemical resistant (alcohol/bleach wipes), high impact strength.
*   **Form Factor:** "Handheld" style vertical box with a hook at the bottom.
    *   *Dimensions (Approx):* 120mm (H) x 70mm (W) x 35mm (D).
*   **Assembly:** 2-part Snap-fit or Screw-together (4x M3 Stainless Steel screws from the back).
*   **Sealing:** Silicone O-ring groove around the perimeter of the mating surfaces.

## 3. Mounting Mechanism (Top)
The device needs to hang *from* the bed rail.
*   **Option A: Integrated Hook:**
    *   A large, robust hook molded into the back of the case.
    *   *Pros:* Cheap, no moving parts.
    *   *Cons:* Might not fit all rail shapes; can slide.
*   **Option B: Adjustable Clamp (Recommended):**
    *   A "C-clamp" style mechanism attached to the back.
    *   Rotatable knob to tighten onto the rail (0.8" - 1.5" range).
    *   Rubber pads inside the clamp to prevent slipping and scratching the bed rail.

## 4. Load Cell Integration (Ultra-Compact Button)
To achieve a minimal device footprint, we utilize a **Compression Load Button** (Coin-style sensor) instead of a large beam.

1.  **Sensor Selection:** **TE FX1901** or Generic **10-20mm Load Button** (Range: 10-20lb / 5-10kg).
    *   *Size:* ~15mm Diameter.
    *   *Type:* Compression Force Sensor.
2.  **Mechanical Interface ("Pull-to-Push"):**
    *   **Shelf:** The sensor sits on a structural PCB or plastic shelf inside the case, facing **UP**.
    *   **Hook Shaft:** Passes *through* a hole next to (or under) the sensor assembly.
    *   **Bridge/Yoke:** The top of the hook connects to a rigid "Bridge" piece that spans over the sensor.
    *   **Action:** When the bag pulls the hook **DOWN**, the Bridge presses **DOWN** onto the sensor's "button" surface.
3.  **Sealing:**
    *   Standard O-ring or Rubber Boot where the hook shaft exits the bottom shell.
4.  **Overload Protection:**
    *   **Hard Stop:** The Bridge hits the PCB/Shelf supports after 0.5mm of travel, preventing sensor crushing during gross overload.

## 5. Tube Management (Strain Relief) - Critical
*   **Problem:** Tension on the catheter tube (from patient movement) creates variable lift/force on the bag, corrupting weight data.
*   **Solution:** Integrated **Tube Retention Clip** molded into the **Stationary Front Shell**.
*   **Usage:** 
    1.  The nurse clips the incoming catheter tube into this holder.
    2.  This absorbs all pulling forces into the device body (and bed rail).
    3.  A consistent "slack loop" of tubing hangs between the Clip and the Bag Inlet, ensuring only the bag's weight is measured.

## 6. RF & Antenna Placement
*   **Location:** The antenna (Flex PCB type) must be adhered to the **Top Front** of the inside of the plastic shell.
*   **Separation:** Keep the antenna at least **20mm away** from the metal Bed Rail Clamp mechanism (Back) and the Load Cell/Hook assembly (Bottom).
*   **Orientation:** Vertical polarization is preferred for best omnidirectional coverage in a single-story ward.

## 7. User Interface & Battery
*   **Display:** E‑Ink (GDEY0213B74) mounted behind a clear PC (Polycarbonate) window glued into the Front Shell. The window should have a black masked border to hide the glue line.
*   **Buttons:** **Membrane Keypad** (Stick-on) on the front surface.
    *   *Routing:* The FPC tail from the keypad must pass through a sealed slot (potted with resin) to reach the PCB.
    *   *Functions:* "Tare/Zero" (Short Press), "Range Toggle" (Long Press).
*   **Battery (Current Plan):**
    *   The battery pack is in a **separate battery case** and connects to the PCB via a **2‑wire JST‑PH cable**.
    *   *Why:* reduces PCB size, reduces mechanical constraints on the PCB, and allows battery service without opening the electronics compartment.
*   **USB‑C (Development):**
    *   USB‑C should be accessible for bench power + console + flashing (via UART bootloader).
    *   For IP‑rating, consider a gasketed rubber plug or a recessed port with a sealing cap.

## 7. 3D Printing for Prototype
*   **Process:** FDM or SLA.
*   **Material:** PETG (easy to print, durable) or Resin (SLA for smooth finish).
*   **Draft Angle:** If moving to injection molding later, ensure vertical walls have 1-2 degrees of draft.

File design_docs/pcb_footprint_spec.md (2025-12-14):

# PCB Physical Specification (Current Plan)

This spec replaces earlier drafts that assumed a PCB‑mounted AA holder. In the current plan:
- The **battery is off‑board** (separate battery case) and connects via a **2‑wire JST‑PH** cable.
- The **display is off‑board** (mounted in the enclosure front) and connects via a **24‑pin FPC** cable.

## 1. Board Outline (Target)
- **Goal:** make the PCB as small as practical while keeping routing sane and respecting RF/HV keepouts.
- **Current generator default:** 60mm (W) × 80mm (H) rectangle (USB‑C centered on the bottom short edge, STM32F042 debug bridge + LDO/Schottky just above it, JST‑PH battery at the lower‑left, load cell on the left edge, FPC on the right edge, u.FL near the top edge).
- **Target after tightening:** shrink to the minimal envelope around connectors + functional blocks.

## 2. Edge Anchors (Must‑Haves)
- **USB‑C:** centered on one short edge (development power + console + flashing via UART bootloader).
- **FPC (Display):** placed on an edge so the cable exits cleanly to the display.
- **Battery JST:** currently on the bottom edge offset from USB to reduce crowding; keep clearance for harness strain relief.
- **u.FL:** on the top edge near RAK3172 RF pin (short 50 Ω feed).
- **Load cell header:** edge accessible for harness / strain relief.

## 3. Keepouts / Constraints
- **RF:** keep the RAK3172 RF feed short; use ground stitching; avoid copper “slots” under the feed.
- **E‑paper HV:** booster loop and HV caps stay close to the FPC pins; keep noisy HV away from HX711 analog inputs.
- **Thermal:** USB power entry (LDO + ORing diode) is a heat source; keep it away from HX711 and from the RF feed, and give it copper to spread heat.

## 4. Silkscreen / Assembly
- Reference designators (`U*`, `R*`, `C*`, `J*`) must be visible on `F.SilkS` and placed clear of pads so assembly/debug is possible without the 3D viewer.

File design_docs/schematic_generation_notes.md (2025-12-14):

# Programmatic Schematic Generation Notes

This repo generates the KiCad schematic *from code* (`tools/gen_urine_schematic.py`) to keep the design reproducible and reviewable.

## Current design intent (high level)
- **Dev interface:** USB‑C + STM32F042 bridge (power + USB‑UART console + CMSIS‑DAP SWD + UART bootloader flashing)
- **Field power:** external battery pack via 2‑wire JST‑PH
- **Display:** off‑board e‑paper connected via 24‑pin FPC cable (PCB only hosts the connector + required HV booster parts)
- **RF:** u.FL connector and short 50 Ω feed from RAK3172

## Generator conventions
- Snap all placements to a 1.27 mm grid.
- Use per‑pin stubs + global labels (readable PDFs; minimizes accidental wire merges).
- Add `PWR_FLAG` on driven rails to keep ERC clean.
- Add explicit `no_connect` markers for unused pins.
- Keep reference/value/footprint text away from pins so exported PDFs are readable.

## How to regenerate everything (headless)
Use the single entrypoint script:
```bash
bash tools/regen_kicad_project.sh
```
This regenerates the schematic, runs ERC, generates/places/routs the PCB, runs DRC, exports PDFs/PNGs, and produces JLCPCB fabrication artifacts.

## Notes
- If ERC shows merged nets, it is usually caused by overlapping stub endpoints; nudging the responsible instance a few grid steps fixes it.
- Keep the schematic “blocky”: USB/Power, RF, HX711 analog, and Display/HV should each read as a separate cluster even in a single‑page sheet.
- USB-C is wired with full D+/D- pins into the STM32F042 bridge (powered from the 3.3 V rail with CC pulldowns) so a single cable provides development power + UART (CDC) + CMSIS‑DAP SWD.

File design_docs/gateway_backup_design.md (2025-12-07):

# Backup Gateway Design (Plan B)

> **⚠️ WARNING: UNVERIFIED DESIGN**
> This design proposal (Plan B) lacks validating datasheets for the core components (**ESP32-S3** and **RAK5146**) in the project repository. It serves as a conceptual backup only. The primary, validated solution is the **RAK7268V2 Commercial Gateway** (see `system_architecture.md` and `datasheets/rak7268v2_datasheet.md`). Implementation of this custom gateway should not proceed without full component validation.

## 1. Objective
To provide a proprietary, cost-effective custom gateway design as a backup to the commercial RAK7268V2. This design focuses on component availability and stripped-down functionality (LoRaWAN Packet Forwarder only).

## 2. Architecture
A **"Hybrid-Gateway"** architecture: High-performance ESP32-S3 drives a standard LoRaWAN Concentrator.

*   **Host Processor:** **Espressif ESP32-S3-WROOM-1-N8R2** (8MB Flash, 2MB PSRAM).
    *   *Interfaces:* SPI (LoRa), SPI/RMII (Ethernet), USB (Debug/Power).
*   **LoRa Concentrator:** **RAK5146** (SPI Version, SX1303).
    *   *Connector:* Standard Mini-PCIe.
*   **Ethernet:** **WIZnet W5500** (SPI) or **LAN8720** (RMII). *Selection: W5500 for simpler SPI routing.*

## 3. Power Design (Critical)
The SX1303 Concentrator bursts up to **500mA**. A standard LDO is insufficient.
*   **Input:** USB-C (5V).
*   **Regulation:** **Buck Converter** (Step-Down) to 3.3V.
    *   **Chip:** **MPS MP2359** (1.2A High Efficiency).
    *   **Inductor:** 4.7uH Shielded Power Inductor.
    *   **Capacitors:** 22uF Ceramic on Input and Output.

## 4. Pin Mapping (ESP32-S3)

| ESP32 Pin | Function | Connection |
| :--- | :--- | :--- |
| **GPIO 1** | SPI_MOSI | **RAK5146 MOSI** & **W5500 MOSI** |
| **GPIO 2** | SPI_MISO | **RAK5146 MISO** & **W5500 MISO** |
| **GPIO 3** | SPI_CLK | **RAK5146 SCLK** & **W5500 SCLK** |
| **GPIO 4** | GPIO | **RAK5146 CS#** (Chip Select) |
| **GPIO 5** | GPIO | **W5500 CS#** (Chip Select) |
| **GPIO 6** | GPIO | **RAK5146 RST** (Reset) |
| **GPIO 7** | GPIO | **W5500 RST** (Reset) |
| **GPIO 8** | GPIO | **W5500 INT** (Interrupt) |
| **GPIO 9** | GPIO | **Status LED** (Green) |
| **GPIO 10** | GPIO | **Error LED** (Red) |
| **USB D+/D-** | USB | **USB-C Connector** (Programming) |

## 5. Mini-PCIe Slot Pinout (RAK5146 Target)
*   **Pin 2 (3.3V):** Connect to MP2359 Output.
*   **Pin 24 (3.3V):** Connect to MP2359 Output.
*   **Pin 52 (3.3V):** Connect to MP2359 Output.
*   **Pin 4, 9, 15, 18, 21... (GND):** Connect to GND Plane.
*   **Pin 19 (SPI_MOSI):** Connect to ESP32 GPIO 1.
*   **Pin 21 (SPI_MISO):** Connect to ESP32 GPIO 2.
*   **Pin 23 (SPI_SCK):** Connect to ESP32 GPIO 3.
*   **Pin 25 (SPI_CS):** Connect to ESP32 GPIO 4.
*   **Pin 17 (RST):** Connect to ESP32 GPIO 6.

## 6. Detailed Bill of Materials (BOM)

| Item | Manufacturer | Part Number | Description | Qty | Unit Cost |
| :--- | :--- | :--- | :--- | :--- | :--- |
| **Host MCU** | Espressif | **ESP32-S3-WROOM-1-N8R2** | Wi-Fi/BLE Module, 8MB/2MB | 1 | $2.80 |
| **Concentrator** | RAKwireless | **RAK5146 (SPI)** | SX1303 LoRaWAN Card | 1 | $45.00 |
| **Ethernet Chip** | WIZnet | **W5500** | SPI to Ethernet Controller | 1 | $1.50 |
| **Ethernet Jack** | Pulse | **J0011D21BNL** | RJ45 with Magnetics | 1 | $1.20 |
| **Buck Converter** | MPS | **MP2359** | 1.2A 3.3V Step-Down | 1 | $0.40 |
| **Inductor** | Generic | **CDRH4D28-4R7** | 4.7uH Power Inductor | 1 | $0.15 |
| **PCIe Socket** | Generic | **AS0B221-S68Q-7H** | 52-Pin Mini-PCIe H=4mm | 1 | $1.00 |
| **USB Connector** | Generic | **Type-C 16-Pin** | Power + Data | 1 | $0.40 |
| **PCB** | JLCPCB | **Custom** | 2-Layer, Thermal Vias | 1 | $3.00 |
| **Enclosure** | Generic | **100x100 ABS** | Waterproof Box | 1 | $5.00 |
| **TOTAL** | | | | | **~$60.45** |

## 7. Layout Guidelines
1.  **Thermal Management:** The MP2359 and RAK5146 generate heat. Place large copper pours on Top and Bottom layers connected by multiple vias under the Mini-PCIe latch area and power regulators.
2.  **Ethernet:** Keep differential pairs (TX+/TX-, RX+/RX-) from the W5500 to the RJ45 jack short and length-matched.
3.  **RF:** The RF is handled on the RAK5146 card, so the baseboard only deals with digital signals. Keep SPI lines direct.

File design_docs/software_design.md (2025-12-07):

# Software & Backend Design

## 1. High-Level Architecture
The software backend transforms raw LoRaWAN packets into actionable medical insights. It is designed to be **containerized (Docker)** for easy on-premise hospital deployment.

```mermaid
graph LR
    A[Gateways] -->|UDP/Semtech Packet Forwarder| B(ChirpStack Network Server)
    B -->|MQTT Publish| C[Python App Controller]
    C -->|Write| D[(PostgreSQL TimescaleDB)]
    C -->|Websocket| E[React Dashboard]
    C -->|HL7v2 / FHIR| F[Hospital EMR System]
```

## 2. Components

### A. LoRaWAN Network Server (LNS)
*   **Choice:** **ChirpStack** (Open Source).
*   **Role:** Manages gateways, authenticates devices (Join Request), decrypts payloads, handles downlink queue.
*   **Integration:** Publishes decrypted events to MQTT topic `application/ID/device/EUI/event/up`.

### B. Application Controller (The "Brain")
*   **Language:** Python (FastAPI or Django) or Node.js.
*   **Functions:**
    *   **MQTT Client:** Subscribes to ChirpStack data.
    *   **Payload Decoder:** Unpacks the 6-byte binary payload into JSON (e.g., `{"volume": 1200, "flow": 50, "alarm": false}`).
    *   **Logic Engine:** 
        *   *Alerts:* If `volume > 1800` -> Send Notification.
        *   *Analytics:* Calculate shift totals (7am-7pm).
    *   **API:** REST API for the frontend to fetch bed status.

### C. Database
*   **Primary:** **PostgreSQL** with **TimescaleDB** extension.
*   **Why:** Medical data is time-series. We need efficient storage of volume readings every hour/minute for history graphs.
*   **Schema Example:**
    ```sql
    TABLE measurements (
        time        TIMESTAMPTZ NOT NULL,
        device_eui  VARCHAR(16),
        patient_id  VARCHAR(50),
        volume_ml   INT,
        flow_rate   INT,
        battery_pct INT
    );
    ```

### D. Frontend Dashboard
*   **Framework:** **React.js** or **Vue.js**.
*   **Views:**
    *   **Ward Map:** Grid view of beds with color codes (Green=OK, Red=Full/Blocked, Yellow=Low Battery).
    *   **Patient Detail:** Line graph of urine output over the last 24h.
    *   **Settings:** "Tare" button (sends LoRaWAN downlink to device), Alarm thresholds.

## 3. Integration with Hospital Systems (EMR)
Hospitals use legacy systems. We need an **Integration Engine**.
*   **Protocol:** **HL7 v2.x** (Most common) or **FHIR** (Modern).
*   **Workflow:**
    1.  Nurse scans Patient Wristband + Device QR code.
    2.  App Server links `Device_A` to `Patient_123`.
    3.  Every hour, App Server generates an **ORU^R01** (Observation Result) HL7 message.
    4.  Sends to Hospital Interface Engine (Mirth Connect / Iguana).

## 4. Deployment Stack (Docker Compose)
```yaml
version: '3'
services:
  chirpstack:
    image: chirpstack/chirpstack:4
    ports: ["8080:8080"]
  
  postgres:
    image: timescale/timescaledb:latest-pg14
    
  app-server:
    build: ./backend
    command: python main.py
    
  frontend:
    build: ./frontend
    ports: ["3000:80"]
```

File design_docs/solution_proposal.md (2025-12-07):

# Hospital Urine Drainage Bag Monitoring System - Solution Proposal

## 1. Executive Summary
This document proposes an optimized solution for the "Intelligent Monitoring Device for Hospital Urine Drainage Bag Volume". The original proposal (BLE + Wi-Fi Gateway) faces challenges regarding signal interference, gateway density, and battery maintenance in a high-density hospital environment. 

**Key Improvements:**
*   **Connectivity:** Switch from **BLE** to **Sub-1GHz (LoRaWAN or Proprietary 915/868 MHz)**.
*   **Infrastructure:** Reduce gateway count from "one per room" to "one per ward/floor".
*   **Sensing:** Stick with **Load Cell (Weight)** for compatibility but implement **Capacitive Sensing** for a next-gen "smart sticker" variant.

## 2. Comparison: Current vs. Proposed

| Feature | Current Idea (BLE + Wi-Fi) | Proposed Solution (Sub-1GHz + Load Cell) |
| :--- | :--- | :--- |
| **Frequency** | 2.4 GHz | Sub-1GHz (e.g., 868/915 MHz) |
| **Interference** | **High** (Wi-Fi, Zigbee, Medical Equip.) | **Low** (Separate from critical Wi-Fi) |
| **Range** | Short (~10-30m) | Long (Hundreds of meters indoor) |
| **Gateway Count** | High (1 per room recommended) | **Low** (1 per ward/floor can handle 1000+ nodes) |
| **Battery Life** | Moderate | **Extended** (Lower transmission power for range) |
| **Cost** | High infra cost (many gateways) | **Lower infra cost** (fewer gateways) |

## 3. Detailed Technical Architecture

### A. Bedside Monitoring Unit (The "Node")
*   **Sensor:** 
    *   *Primary:* **Strain Gauge (Load Cell)**. Robust, works with any standard bag.
    *   *Optimization:* Design the enclosure to clip onto standard bed rails with a retractable hook to minimize profile.
    *   *Alternative:* **Capacitive Level Strip**. A disposable or reusable adhesive strip. Benefits: No mechanical parts, extremely low profile. Drawbacks: Specific to bag geometry.
*   **Microcontroller:** Ultra-low power MCU (e.g., STM32L4 series or TI CC13xx).
*   **Radio:** Sub-1GHz Transceiver (LoRa or FSK). 
    *   *Why:* Penetrates walls easily; avoids the crowded 2.4GHz spectrum used by hospital Wi-Fi and monitoring equipment.
*   **Power:** Li-ion rechargeable or Replaceable AA batteries (2+ years life).
*   **User Interface:** E-Ink Display (Low power, high visibility) or simple LED indicators.

### B. The Gateway (The "Hub")
*   **Radio:** Sub-1GHz Concentrator (8-channel LoRaWAN or Proprietary).
*   **Uplink:** Wi-Fi / Ethernet (PoE preferred for reliability) / Cellular (LTE-M as backup).
*   **Capacity Analysis (High Density Scenario):** 
    *   *Scenario A (Standard):* 100 beds, reporting every **1 hour**.
        *   Load: 100 packets/hour.
        *   Utilization: < 0.2% of gateway capacity.
    *   *Scenario B (Stress Test - Client Request):* 100 beds, reporting every **10 minutes**.
        *   Traffic Load: 100 devices × 6 packets/hour = **600 packets/hour** (10 packets/minute).
        *   *Capability:* A standard 8-channel gateway handles ~60,000+ packets/hour.
        *   *Conclusion:* Even at 10-minute intervals, the network load is **~1%** of the gateway's maximum. The system is "bored" and can easily scale further or handle frequent alarm spikes.

## 4. Functional Workflow
1.  **Measurement:** Device wakes up every minute to sample weight.
2.  **Filtering:** Algorithms filter out "bed shaking" or "patient movement" artifacts.
3.  **Reporting:** 
    *   *Routine:* Transmits volume data once per hour.
    *   *Alarm:* Transmits **immediately** if:
        *   Volume > Threshold (e.g., 80% full).
        *   No flow detected for X hours (potential blockage).
        *   Sudden weight drop (leak/emptied).
4.  **Server:** Central dashboard shows status of all beds in the ward.
5.  **Integration:** HL7/FHIR interface to push data to the Hospital Information System (HIS).

## 5. Cost Analysis (Per 25-Bed Ward)

A direct cost comparison between the two architectures reveals significant savings with the Sub-1GHz approach, primarily driven by infrastructure reduction.

| Item | Option A: BLE + Wi-Fi (Original) | Option B: Sub-1GHz (Proposed) | Notes |
| :--- | :--- | :--- | :--- |
| **Node Hardware** | ~$15.00 / unit | ~$7.00 / unit | *STM32WLE5 SoC reduces BOM cost vs discrete BLE+MCU modules.* |
| **Node Total (25 beds)** | $375.00 | $175.00 | |
| **Gateway Unit Cost** | ~$30.00 (Simple Bridge) | ~$200.00 (Commercial Indoor) | *LoRa gateway is more expensive per unit, but...* |
| **Gateway Quantity** | 25 (1 per room) | 1 (1 per ward) | *...you only need ONE.* |
| **Gateway Total** | **$750.00** | **$200.00** | |
| **Installation (Labor)** | High (25 power outlets, 25 setups) | Low (1 central setup) | *Estimated 10x labor savings.* |
| **Total Hardware Cost** | **~$1,125.00** | **~$375.00** | **~66% Hardware Savings** |

### Economic Conclusion
The **Sub-1GHz solution is ~3x cheaper** in initial hardware capability. 
*   **Infrastructure Savings:** $550 per ward.
*   **Device Savings:** $200 per ward.
*   **Hidden Savings:** drastically reduced IT management (25 IP addresses vs 1 IP address per ward).

## 6. Why this is better
1.  **Reliability:** Sub-1GHz is far less likely to drop connections in a hospital filled with Wi-Fi signals.
2.  **Maintenance:** Fewer gateways mean fewer points of failure and less IT management overhead.
3.  **Scalability:** Easier to deploy. Just plug in one gateway at the nurses' station and deploy nodes in rooms.

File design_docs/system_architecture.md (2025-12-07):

# System Architecture Design
## Intelligent Hospital Urine Bag Monitoring System

### 1. High-Level Topology
The system follows a **Star-of-Stars** topology typical of LoRaWAN networks. It is designed for high density, deep indoor penetration, and low power consumption.

```mermaid
graph TD
    subgraph "Patient Room (The Node)"
        A[Urine Bag] -->|Weight| B(Smart Monitor Device)
        B -->|Sub-1GHz RF| C
    end

    subgraph "Ward Level (The Infrastructure)"
        C[LoRaWAN Gateway] -->|Ethernet/PoE| D[Hospital Network Switch]
    end

    subgraph "Server Room / Cloud (The Backend)"
        D --> E[Network Server LNS]
        E -->|MQTT| F[Application Server]
        F --> G[Database]
        F --> H[Hospital Information System HIS]
    end

    subgraph "Nurses Station"
        F --> I[Dashboard / Tablet]
        F --> J[Alert System Pager/Light]
    end
```

### 2. Data Flow Architecture

1.  **Sensing Layer (Edge):**
    *   **Input:** Physical weight of urine bag.
    *   **Processing:** ADC conversion (HX711), artifact filtering (removing motion noise), formatting payload.
    *   **Output:** Encrypted LoRaWAN packet (Payload: `Volume_mL`, `Battery_%`, `Status_Flags`).

2.  **Transport Layer:**
    *   **Protocol:** LoRaWAN 1.0.3 or 1.1 (Class A devices).
    *   **Frequency:** Region specific (e.g., US915, EU868).
    *   **Gateway Connectivity Models (Select based on Hospital Infrastructure):**
        *   **Option 1: PoE Line (Preferred):**
            *   **Data:** Ethernet.
            *   **Power:** 802.3af/at PoE from Switch or Injector.
            *   **Pros:** Single cable, high reliability, no separate power supply needed.
        *   **Option 2: Wi-Fi Line:**
            *   **Data:** Wi-Fi (WPA2/WPA3 Enterprise).
            *   **Power:** 12V DC Adapter or USB-C.
            *   **Pros:** Flexible placement where Ethernet drops are missing.
    *   **Gateway Hardware:** **RAK7268V2** (Supports both Ethernet/PoE and Wi-Fi/DC out of the box).

3.  **Network Layer (LNS):**
    *   **Software:** ChirpStack (Self-hosted for privacy) or The Things Stack Enterprise.
    *   **Functions:** Deduplication (if multiple gateways hear a node), Authentication (OTAA), Decryption (AppSKey), Data forwarding via MQTT/Webhooks.

4.  **Application Layer:**
    *   **Business Logic:**
        *   Decodes binary payload.
        *   Calculates urine flow rate (mL/hour).
        *   Checks thresholds (Full > 80%, Flow < 10mL/h for 2 hours).
        *   Manages patient-to-device mapping.
    *   **Storage:** Time-series database (InfluxDB) for sensor data; Relational DB (PostgreSQL) for patient/device management.

### 3. Security Architecture
Given the medical context (HIPAA/GDPR considerations), security is paramount, even though the raw data (weight) is not PII until associated with a patient record.

*   **Device Level:** 
    *   **AES-128 Encryption:** Native to LoRaWAN (NwkSKey for network, AppSKey for payload).
    *   **Hardened Firmware:** Read-out protection enabled on STM32 to prevent cloning.
*   **Key Management & Provisioning:**
    *   **OTAA (Over-the-Air Activation):** Devices are provisioned with a unique `DevEUI`, `JoinEUI` (AppEUI), and `AppKey` at the factory.
    *   **Ownership:** The Hospital IT department (or the Service Provider) owns the **Join Server**. Keys are not shared with third-party network operators if using a private ChirpStack instance.
    *   **Lifecycle:** Keys are rotated only upon device reset/re-join. Compromised devices can be blacklisted by `DevEUI` in the LNS.
*   **Network Level:**
    *   **Private Deployment:** Gateways point to a local IP, keeping data within the hospital intranet.
    *   **TLS/SSL:** All traffic from Gateway to Server and Server to UI is encrypted.
*   **Application Level:**
    *   **Role-Based Access Control (RBAC):** Nurses view ward status; Admins manage devices.
    *   **Audit Logs:** Track who acknowledged alarms.

### 4. Scalability Strategy
*   **Ward-by-Ward:** Each ward is a logical "Application" in the LNS.
*   **Capacity:** A single backend server (Dockerized) can handle 10,000+ devices.
*   **Redundancy:** Deploy 2 gateways per critical floor for overlapping coverage.

### 5. Network Health & Reliability (Gateway: RAK7268V2)
To ensure system uptime in a critical hospital environment, the following reliability features are enabled:

*   **Gateway Self-Healing (Ping Watchdog):**
    *   **Mechanism:** The RAK7268V2 "Ping Watchdog" feature periodically pings a known reliable IP (e.g., LNS or 8.8.8.8).
    *   **Action:** If connectivity fails for a set duration, the gateway automatically reboots to clear potential firmware/modem hangs.
*   **Uplink Failover (Backhaul Redundancy):**
    *   **Primary:** Ethernet (PoE) / Wi-Fi.
    *   **Backup:** LTE Cat 4 (via RAK7268CV2 variant) if the hospital network goes down.
    *   **Configuration:** "Uplink Backup" mode is enabled in WisGateOS 2.
*   **Data Buffering:**
    *   **Local Storage:** The gateway buffers LoRaWAN packets in its "Packet Forwarder" buffer (SD card backed) if the backhaul is temporarily unavailable, preventing data loss during short outages.
*   **LNS Monitoring:**
    *   **Keep-Alives:** The LNS tracks the gateway's "last seen" status (via UDP Keep-Alives or MQTT Pings).
    *   **Alerting:** If a gateway is offline for >5 minutes, the Application Server triggers an alert to the IT maintenance team.

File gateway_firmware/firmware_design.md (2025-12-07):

# Plan B Gateway Firmware Design (ESP32-S3 + RAK5146 + W5500)

## 1. Architecture
The firmware is built on the **Espressif IoT Development Framework (ESP-IDF)**. It acts as a transparent bridge between the LoRa concentrator (RF) and the Network Server (IP).

### Core Components
1.  **Main Application:** Initializes hardware, manages the packet forwarder loop, and handles system health (LEDs, Watchdog).
2.  **HAL Layer (Hardware Abstraction):**
    *   **SPI Arbiter:** Manages access to the shared SPI bus for RAK5146 and W5500.
    *   **RAK5146 Driver:** Wraps the Semtech SX1302/SX1303 HAL library.
    *   **W5500 Driver:** Uses the standard ESP-IDF `esp_eth` component or WIZnet driver.
3.  **LoRa Packet Forwarder (Semtech):**
    *   **Upstream:** Polls the concentrator for RF packets -> Encapsulates in JSON/UDP -> Sends to LNS.
    *   **Downstream:** Listens for UDP from LNS -> Schedules TX on concentrator.

## 2. Pin Mapping (Matches `gateway_backup_design.md`)

| ESP32-S3 Pin | Function | Device |
| :--- | :--- | :--- |
| GPIO 1 | SPI_MOSI | Shared |
| GPIO 2 | SPI_MISO | Shared |
| GPIO 3 | SPI_CLK | Shared |
| GPIO 4 | CS | **RAK5146** |
| GPIO 5 | CS | **W5500** |
| GPIO 6 | RST | **RAK5146** |
| GPIO 7 | RST | **W5500** |
| GPIO 8 | INT | **W5500** |

## 3. Implementation Plan
Since we are simulating the build environment (no physical ESP32 connected), we will implement the **Main Application Structure** and **Mock Drivers** to demonstrate the logic.

### Directory Structure
```
/gateway_firmware
├── CMakeLists.txt
├── main/
│   ├── CMakeLists.txt
│   ├── main.c              # Entry point
│   ├── loragw_hal.c        # Mock SX1303 HAL
│   ├── packet_forwarder.c  # Packet handling logic
│   └── network_manager.c   # Ethernet/WiFi logic
└── components/             # (Optional custom components)
```

## 4. Logical Flow
1.  **Boot:** Init SPI, Reset W5500, Reset RAK5146.
2.  **Network Connect:**
    *   Try Ethernet (W5500) via DHCP.
    *   If fail, try Wi-Fi (Fallback).
    *   Wait for IP address.
3.  **Concentrator Init:**
    *   Load calibration/config (EU868/US915 params).
    *   Start SX1303.
4.  **Forwarder Loop:**
    *   **Fetch:** `lgw_receive()` from concentrator.
    *   **Process:** If packet exists, format JSON (Semtech UDP Protocol).
    *   **Send:** `sendto()` UDP packet to LNS IP:1700.
    *   **Receive:** Non-blocking `recvfrom()` for Downlinks.
    *   **Heartbeat:** Send status JSON every 30s.

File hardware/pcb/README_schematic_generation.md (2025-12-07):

# Programmatic KiCad Schematic Generation (urine_monitor.kicad_sch)

This project auto-generates the schematic instead of hand-wiring in the GUI. The generator lives in `tools/gen_urine_schematic.py` and produces `hardware/pcb/urine_monitor.kicad_sch`, plus a verification SVG.

## Dependencies
- KiCad 7/8/9 CLI on macOS (path: `/Applications/kicad/kicad.app/Contents/MacOS/kicad-cli`).
- KiCad symbol libraries available at `/Applications/kicad/kicad.app/Contents/SharedSupport/symbols`.
- Python 3.9+.

## One-shot regeneration
```bash
python tools/gen_urine_schematic.py
/Applications/kicad/kicad.app/Contents/MacOS/kicad-cli sch export svg hardware/pcb/urine_monitor.kicad_sch -o hardware/pcb/schematic_auto.svg
```
Outputs:
- `hardware/pcb/urine_monitor.kicad_sch`
- `hardware/pcb/schematic_auto.svg/urine_monitor.svg` (quick visual check)
- Netlist can be exported with `kicad-cli sch export netlist ...`.

## How the generator works
- **Symbol sources**: It embeds required symbols directly into the schematic to avoid library path issues. Sources include:
  - Project-specific symbols: `hardware/pcb/project_lib.kicad_sym`.
  - KiCad libraries: `Analog_ADC`, `Connector_Generic`, `Connector`, `Device`, `Transistor_FET`, `Regulator_Switching`, `Regulator_Linear`, `Switch`, `power`.
- **Footprints**: A `FOOTPRINTS` map in the script assigns realistic footprints per instance (SOIC-16 for HX711, SOT-23 for FETs, 0603 R/C, SOD-123 diodes, SC70-6 boost, SOT-23-5 LDO, USB-C receptacle, etc.).
- **Instances**: Each component is instantiated with a reference designator, symbol name, and a coarse XY placement. UUIDs are auto-assigned.
- **Nets and wiring**:
  - A net map (`N`) lists `(ref, pin)` pairs per net.
  - Each pin gets a real wire segment to a shared anchor for that net; one label sits on the anchor. This is what fixes the “no wires/disconnected nets” problem—labels alone were not enough.
  - Wires are emitted in horizontal/vertical (Manhattan) segments to reduce crossing through symbols; the orthogonal style is for readability, not correctness (the key fix was adding real wire geometry to an anchor).
  - Pin snapping: the first segment starts exactly at the pin’s coordinate and extends outward (non-zero length) before heading to the anchor, which avoids the “wire ends on the pin body but isn’t connected” failure.
  - This approach addresses two earlier failure modes:
    * **“No chip”/missing symbols in CLI**: symbols are embedded into `lib_symbols` inside the schematic, so `kicad-cli` resolves them without external paths.
    * **“No wires”/nets missing in netlist**: per-pin wires to an anchor plus a single anchor label ensure KiCad forms the intended nets.

## Customizing symbols and footprints
1) Add or edit symbols:
   - Project symbols: `hardware/pcb/project_lib.kicad_sym`.
   - KiCad symbols: ensure the library path is listed in `LIB_PATHS` inside the script.
2) Assign footprints:
   - Extend the `FOOTPRINTS` dict with `ref: "Library:Footprint"` entries.
   - KiCad will carry these into the netlist and PCB association.

## Adding or changing nets
1) Edit the `add(net, ref, pin)` declarations in `tools/gen_urine_schematic.py`.
2) Regenerate the schematic (see commands above).
3) Export SVG to visually verify and adjust anchor spacing if wires are too close to symbols.

## Verification
- Visual: open `hardware/pcb/schematic_auto.svg/urine_monitor.svg`.
- Netlist: `kicad-cli sch export netlist hardware/pcb/urine_monitor.kicad_sch -o /tmp/urine.net`.
- ERC: `kicad-cli sch erc hardware/pcb/urine_monitor.kicad_sch` (expect warnings until all nets are finalized).

## Tips for refinement
- If anchors sit too close to symbols, increase the `margin` in `emit_net_manhattan` or choose per-net offsets.
- For strict style (no wires through symbols), bias anchors to the side where the majority of pins exit (already done in the script) and increase margin in dense areas.
- Keep coordinates coarse; the goal is connectivity and repeatability. Final drafting can be done in KiCad if desired, but regeneration should remain deterministic.

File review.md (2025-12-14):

# Project Status Review

## Hardware
- **Schematic:** `hardware/pcb/urine_monitor.kicad_sch`
  - Status: generated by `tools/gen_urine_schematic.py` and validated via KiCad CLI ERC.
  - Dev I/O: USB‑C + STM32F042 bridge (USB CDC console + CMSIS‑DAP SWD; UART bootloader flashing).
  - Field I/O: JST‑PH 2‑wire battery connector; u.FL antenna; 24‑pin FPC display connector.
- **PCB:** `hardware/pcb/urine_monitor.kicad_pcb`
  - Status: generated/placed/routed headlessly (`tools/auto_layout_pcb.py` + FreeRouting) and validated via KiCad CLI DRC.
  - Artifacts: board/schematic PNGs + a JLC fabrication zip are produced by `tools/regen_kicad_project.sh`.

## Firmware
- **Source:** `firmware/`
- **Build:** `CMake` + `STM32Cube` structure.
- **Status:** Compiles successfully (mock HAL).
  - Dev console intended on `UART2` via the on‑board STM32F042 bridge (USB CDC) or an external CMSIS‑DAP/SWD probe (see `design_docs/firmware_design.md`).

## Mechanical
- **Case:** `mechanical/scad/monitor_case.scad`
- **Status:** OpenSCAD script valid. Generates Front and Back shells with display cutout.

## Next Steps
1. **Bring schematic to “production‑ready”:** remove legacy debug headers, implement SSD1680 HV booster circuit, ensure battery sense measures `BAT`.
2. **Improve PCB professionalism:** visible silkscreen refs, tighter board outline, cleaner placement (USB/thermal, RF, analog, HV separated).
3. **Firmware:** enable UART2 console and document/automate UART‑bootloader flashing flow.

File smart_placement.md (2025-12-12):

Here’s a practical recipe for auto‑placing schematic blocks so pages look “hand‑crafted” but come from an algorithmic flow.

---

# Multi‑objective schematic auto‑placement (readability → grouping → space)

**Goal order (hard → soft):**

1. Label readability (no overlaps, sane angles)
2. Preserve functional grouping (keep net clusters tight)
3. Minimize whitespace before deciding to split pages

## Core model

* Treat each symbol `i` with a **rect bbox** `(xi, yi, wi, hi)` and **label bboxes** (refdes, pin names).
* Nets define a **graph**: nodes = symbols, edges = electrical connections (optionally hyperedges per net).
* Page is a rectangular canvas with soft margins.

### Cost terms (weighted sum; enforce priority via large weight ratios W1 ≫ W2 ≫ W3)

* **Readability** `C_read`

  * Label overlap: sum IoU between all label bboxes (penalty)
  * Label–symbol overlap (penalty)
  * Label angle penalty: prefer 0°, 90° (hinged L1 penalty from nearest canonical angle)
  * Minimum label font size violations (big penalty)
* **Grouping** `C_group`

  * Net tension: Σ over edges `||pos(i) − pos(j)||` with edge weights (e.g., bus > power > signal)
  * Cluster compactness: for detected communities (Louvain/Leiden on net graph), Σ pairwise distances to cluster centroid
* **Space/page usage** `C_space`

  * Dead‑space entropy: encourage even packing by penalizing large empty rectangles
  * Aspect ratio deviation from target (e.g., A4 landscape)
  * Page overflow penalty (very large if any bbox leaves page)

**Total cost:**
`C = W1*C_read + W2*C_group + W3*C_space`, with `W1:W2:W3 ≈ 100:10:1`.

## Optimizer: simulated annealing (SA)

* **State:** positions (and optional orientations) of symbols; label anchor/angle choices.
* **Moves:**

  * Nudge symbol (small random Δx, Δy)
  * Swap two symbols’ regions within a cluster
  * Rotate/flip symbol if allowed (orthogonal orientations)
  * Re‑anchor a label (top/bottom/left/right) and snap angle to {0°, 90°} with jitter
* **Schedule:** geometric `T ← αT` (α≈0.95 per k iterations), reheats if stuck.
* **Acceptance:** Metropolis on ΔC (always accept if readability improves; use **lexicographic** accept to respect priorities).

## Page splitting (only after good packing)

1. Run SA to convergence on a **single large canvas**.
2. Build a **connection‑cut graph**: edge weight between clusters = number/importance of inter‑cluster nets.
3. Solve a **balanced min‑cut** (or recursive bisection) to partition clusters into pages while:

   * respecting maximum page density (total bbox area / page area)
   * minimizing cut edges (prefer connector/bus stubs at page boundaries)
4. For each page, re‑run a **local SA** with fixed node set to polish.

## Practical heuristics that help a lot

* **Grid‑snap** symbols to 8–16 px; free‑place labels within a small continuous window—this kills micro‑overlaps.
* **Orthogonal label angles only** (0/90) unless absolutely needed; dramatically improves legibility.
* **Pin‑side bias**: penalize routes crossing through bboxes by preferring placements that keep likely wires on free sides.
* **Power/ground rails**: treat as “gravity fields” (attract VCC up, GND down) to get familiar visual structure.
* **Buses first**: place bus‑heavy clusters along a spine; satellites arrange around it.

## Tiny reference implementation (pseudo‑Python)

```python
def cost(state):
    C_read = label_overlaps(state) + label_angle_penalty(state) + label_on_symbol_overlap(state)
    C_group = net_tension(state) + cluster_compactness(state)
    C_space = whitespace_penalty(state) + aspect_ratio_penalty(state) + overflow_penalty(state)
    return 100*C_read + 10*C_group + 1*C_space

def anneal(state, T0=1.0, T_min=1e-3, alpha=0.95):
    T, best = T0, state.copy()
    Cb = cost(best)
    while T > T_min:
        for _ in range(200):  # inner loop
            s2 = propose_move(state)  # nudge/swap/re-anchor/rotate
            dC = cost(s2) - cost(state)
            # lexicographic accept: prioritize readability
            if improves_readability(s2, state) or dC < 0 or rand() < exp(-dC/T):
                state = s2
                if cost(state) < Cb:
                    best, Cb = state.copy(), cost(state)
        T *= alpha
    return best
```

## Testing & acceptance (fast)

* **Unit checks:** no label overlaps; all symbols in page; min text size met.
* **Graph metrics:** average edge length within cluster ≤ threshold; cut‑edge count per page minimized.
* **Golden examples:** run on 3–5 hand‑drawn schematics and compare:

  * wire crossings vs. baseline
  * page count and fill factor (aim 65–85%)
  * review time by a human (qualitative)

## Integration hooks (KiCad/EDA)

* Export/import **bboxes + pins** from the schematic format (JSON/IPC).
* Keep a deterministic **seed** and write back **placements + label anchors**; leave wiring to your router, but your cost’s “pin‑side bias” will make routing cleaner.
* Store **cluster IDs** in fields so page‑splitter is repeatable.

If you want, I can turn this into a runnable Python script that ingests a simple JSON of symbols/nets and outputs placed coordinates + page assignments.

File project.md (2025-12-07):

medical monitoring project
Project Requirement: Intelligent Monitoring Device and System for Hospital Urine Drainage Bag Volume

Background:
Urine bag monitoring in hospitals has not yet been incorporated into the digital management system.
The needs include:

Reporting the urine volume on the hour.

Early warning and alarm when the bag is nearly full or full.

Each room has approximately 25 beds.

Selected Design Solution:
Sub-1GHz (LoRaWAN) Weighing Node + Floor-level Gateway.

A LoRaWAN weighing device is installed at each bed.
It includes:

A low-power E-Ink display showing the current urine volume

A zero-setting button (also used as the start button)

Battery power supply (AA or Li-SoCl2)

An electronic weighing (pressure) sensor with 24-bit ADC

A hook for hanging the urine bag

A mechanical clamp for fixation to bed rails

The floor-level gateway includes:

A LoRaWAN Concentrator (Sub-1GHz)

Ethernet/Wi-Fi/Cellular connectivity to the Hospital Network

Capacity to handle an entire ward (25-100+ devices)

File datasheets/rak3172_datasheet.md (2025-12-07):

# RAK3172 WisDuo LoRaWAN Module Datasheet | Specs & Features

## Overview

### Description

The RAK3172 is a low-power, long-range transceiver module based on the STM32WLE5CC chip. It offers an easy-to-use, compact, and low-power solution for long-range wireless data applications. This module complies with Class A, B, and C of the LoRaWAN 1.0.3 specifications. It can effortlessly connect to various LoRaWAN server platforms, including TheThingsNetwork (TTN), Chirpstack, Actility, etc. Additionally, it supports LoRa Point-to-Point (P2P) communication mode, enabling the rapid implementation of customized long-range LoRa networks.

You can configure the module's mode and operation using AT commands via a UART interface. RAK3172 also offers low-power features, making it well-suited for battery-powered applications.

### Features

*   Based on STM32WLE5CCU6
*   LoRaWAN 1.0.3 specification compliant
*   Supported bands: EU433, CN470, IN865, EU868, AU915, US915, KR920, RU864, and AS923-1/2/3/4
*   LoRaWAN activation via OTAA/ABP
*   LoRa Point-to-Point (P2P) communication
*   Custom firmware using Arduino via RUI3 API
*   Easy to use AT command set via UART interface
*   Long-range - greater than 15 km with optimized antenna
*   ARM Cortex-M4 32-bit
*   256 kbytes flash memory with ECC
*   64 kbytes RAM
*   Ultra-low-power consumption of 1.69 μA in sleep mode
*   Supply Voltage: 2.0 V ~ 3.6 V
*   Temperature Range:
    *   RAK3172: -20° C ~ 85° C
    *   RAK3172-T: -40° C ~ 85° C

**NOTE**
There are two certification variants available for the RAK3172 Module: (1) with the CE & UKCA Certification Mark and (2) with FCC, IC, & RCM Certification Mark.

If you need a LoRa module with BLE 5.0 capability, you can check out the RAK11720. The RAK11720 is pin-to-pin compatible with the RAK3172 and has additional pins for ground and a BLE RF antenna port.

**warning**
Temperature ratings:
RAK3172 is -20° C to 85° C
RAK3172-T is -40° C to 85° C

## Specifications

This section covers the hardware and software specifications of the RAK3172. Also, it includes the block diagram and an updated firmware link for the RAK3172 WisDuo Module.

### Overview

### Block Diagram

RAK3172 System Block Diagram Figure 1: RAK3172 System Block Diagram

### Hardware

The hardware specification discusses the interfaces, pinouts, and their corresponding functions and diagrams. It also covers the parameters of both RAK3172 modules in terms of RF, electrical, mechanical, and operating characteristics.

#### Interfaces

| Module Interfaces | RAK3172 |
| :--- | :--- |
| UART2/LPUART1 | UART1 |

#### Sub-GHz SPI interface

A dedicated internal SPI interface called SUBGHZSPI is used to communicate with the RF subsystem of the STM32WLE5CCU6.

#### Pin Definition

Board Pinout for RAK3172 Figure 2: Board Pinout for RAK3172

**warning**
When using RF pin for antenna and not the IPEX connector variant, there are design considerations to make sure optimum RF performance.

*   RF traces must be away from interference (switching nodes of DC-DC supplies, high current/voltage pulses from controllers of inductive loads like motors, signal generators, etc.).
*   RF traces must have 50 Ohm impedance. It is advisable to use impedance simulation software tools to achieve this requirement.
*   If using an external antenna connector, place it close to the RF pin.
*   Ground plane optimization is critical for certain antenna types, such as monopoles.
*   GND traces used for RF path return must be directly connected to the GND plane and not treated as thermal reliefs.
*   It is recommended that RF traces be routed in a curve rather than at a sharp 90 degrees.

In addition, with a commitment to making IoT easy, RAK offers a dedicated service for Antenna RF Design which includes PCB design, tuning, matching, and RF testing.

| Pin No. | Name | Type | Description |
| :--- | :--- | :--- | :--- |
| 1 | PA3/UART2_RX  | I | Reserved - UART2/LPUART1 Interface (AT Commands and FW Update) |
| 2 | PA2/UART2_TX  | O | Reserved - UART2/LPUART1 Interface (AT Commands and FW Update) |
| 3 | PA15/PIN_A4 | I/O  | GPIO and ADC |
| 4 | PB6/UART1_TX  | O | UART1 Interface |
| 5 | PB7/UART1_RX  | I | UART1 Interface |
| 6 | PA1 | I/O  | GPIO only |
| 7 | PA13/SWDIO | | Reserved - SWD debug pin (SWDIO) |
| 8 | PA14/SWCLK | | Reserved - SWD debug pin (SWCLK) |
| 9 | PA12/I2C_SCL  | I/O  | GPIO and I2C (SCL) |
| 10 | PA11/I2C_SDA  | I/O  | GPIO and I2C (SDA) |
| 11 | GND | | Ground connections |
| 12 | RF | | RF Port (only available on RAK3172 No-IPEX connector variant)  |
| 13 | PA7/SPI1_MOSI | I/O  | GPIO and SPI (MOSI) |
| 14 | PA6/SPI1_MISO | I/O  | GPIO and SPI (MISO) |
| 15 | PA5/SPI1_CLK  | I/O  | GPIO and SPI (CLK) |
| 16 | PA4/SPI1_NSS  | I/O  | GPIO and SPI (NSS) |
| 17 | GND | | Ground connections |
| 18 | GND | | Ground connections |
| 19 | PA8 | I/O  | GPIO only |
| 20 | PA9 | I/O  | GPIO only |
| 21 | BOOT0 | | Boot0 mode enable pin - high active |
| 22 | RST | | MCU Reset (NRST) |
| 23 | GND | | Ground connections |
| 24 | VDD | | VDD - Voltage Supply |
| 25 | PA10/PIN_A3 | I/O  | GPIO and ADC |
| 26 | PB2/PIN_A2 | I/O  | GPIO and ADC |
| 27 | PB12 | I/O  | 10 kΩ internally pulled-up for high freq variant or pulled-down for low freq variant |
| 28 | GND | | Ground connections |
| 29 | PA0 | I/O  | GPIO only |
| 30 | PB5 | I/O  | GPIO only |
| 31 | PB4/PIN_A1 | I/O  | GPIO and ADC |
| 32 | PB3/PIN_A0 | I/O  | GPIO and ADC |

#### RF Characteristics

The RAK3172 supports two different frequency variations: RAK3172(L) Low Radio Frequency and RAK3172(H) High Radio Frequency.

**NOTE**
Performance test and evaluation of RAK3172-T (with TCXO), can be found on the RAK3172-T TCXO Verification Report

#### Operating Frequencies

| Module | Region | Frequency |
| :--- | :--- | :--- |
| RAK3172(L)  | Europe | EU433 |
| | China | CN470 |
| RAK3172(H)  | Europe | EU868 |
| | North America | US915 |
| | Australia | AU915 |
| | Korea | KR920 |
| | Asia | AS923-1/2/3/4 |
| | India | IN865 |
| | Russia | RU864 |

#### Electrical Characteristics

##### Operating Voltage

| Feature | Minimum | Typical | Maximum | Unit |
| :--- | :--- | :--- | :--- | :--- |
| VCC | 2.0 | 3.3 | 3.6 | Volts (V) |

##### Operating Current

| Feature | Condition | Minimum | Typical | Maximum | Unit |
| :--- | :--- | :--- | :--- | :--- | :--- |
| Operating Current | TX Mode 87 (@ 20 dBm 868 Mhz) | | | mA |
| | RX Mode | | 5.22 | | mA |

##### Sleep Current

| Feature | Condition | Minimum (2.1 V) | Typical (3.3 V) | Maximum | Unit |
| :--- | :--- | :--- | :--- | :--- | :--- |
| Current Consumption | EU868 | - | 1.69 | - | μA |
| | US915 | - | 1.69 | - | μA |
| | CN470 | - | 1.69 | - | μA |

**NOTE**
For the reference application schematic of RAK3172 with minimum components requirements, refer to the RAK3272S Breakout Board Datasheet.

#### Mechanical Characteristics

##### Module Dimensions

RAK3172 Physical Dimension Figure 3: RAK3172 Physical Dimension

##### Layout Recommendation

RAK3172 Layout Figure 4: RAK3172 Layout

#### Environmental Characteristics

##### Operating Temperature

| Module | Minimum | Typical | Maximum | Unit |
| :--- | :--- | :--- | :--- | :--- |
| RAK3172 | -20 | 25 | 85 | ° C  |
| RAK3172-T  | -40 | 25 | 85 | ° C  |

##### Storage Temperature

| Feature | Minimum | Typical | Maximum | Unit |
| :--- | :--- | :--- | :--- | :--- |
| Storage Temperature | -40 | | 85 | ° C  |

##### Recommended Reflow Profile

Reflow Profile for RAK3172 Figure 5: Reflow Profile for RAK3172

Standard conditions for reflow soldering:

*   Pre-heating Ramp (A) (Initial temperature: 150° C): 1~2.5° C/sec
*   Soaking Time (T2) (150~180° C): 60~100 sec
*   Peak Temperature (G): 230~250° C
*   Reflow Time (T3) (> 220° C): 30~60 sec
*   Ramp-up Rate (B): 0~2.5° C/sec
*   Ramp-down Rate (C): 1~3° C/sec

### Software

Download the latest RAK3172 WisDuo LoRaWAN Module firmware provided below. The RAK3172(L) and RAK3172(H) use the same firmware, and it will automatically detect the variant of the module being used.

The bin file contains only the application code. You will need the RAK DFU Tool to upload this file to the module.

The hex file contains both the bootloader and the application code. You need to use STM32CubeProgrammer to upload this.

**warning**
Uploading the .hex file via STM32CubeProgrammer will erase all configured data on the device.

RAK3172 uses UART2 serial pins to upload the latest firmware.

**NOTE**
RAK3172 should automatically go to BOOT mode when the firmware is uploaded via RAK DFU Tool or WisToolBox.

If BOOT mode is not initiated, you can manually send AT+BOOT command to start bootloader mode.

#### Firmware

| Model | Version | Source |
| :--- | :--- | :--- |
| RAK3172 (.bin) | RUI3 Application Code only (default baudrate = 115200) | Download |
| RAK3172 (.hex) | RUI3 Bootloader and Application Code(default baudrate = 115200) | Download |
| RAK3172-T (.bin) | RUI3 Application Code only(default baudrate = 115200) | Download |
| RAK3172-T (.hex) | RUI3 Bootloader and Application Code (default baudrate = 115200) | Download |
| RAK3172 (OLD)  | DEPRECATED V1.0.4 (default baudrate = 9600) | Download |

**warning**
There are RAK3172 devices loaded with old firmware versions which are not based on RUI3 (RAKwireless Unified Interface V3). These devices have v1.0.4 and below.

If the host microcontroller code is based on this old firmware, refer to the RAK3172 AT Command migration guide that explains in detail the few differences between the two AT commands set.

## Models and Bundles

### Ordering Information

| P/N | Model | TCXO | Antenna Interface | Frequency | SKU |
| :--- | :--- | :--- | :--- | :--- | :----- |
| RAK3172-8-SM-NI | RAK3172 | Without TCXO | No IPEX | 8XX MHz for RU864/IN865/EU868  | 305044 |
| RAK3172-9-SM-NI | RAK3172 | Without TCXO | No IPEX | 9XX MHz for US915/AU915/KR920/AS923 | 306041 |
| RAK3172-9-SM-NI | RAK3172 | Without TCXO | No IPEX | AS923-1 Japan | 309044 |
| RAK3172-43-SM-NI  | RAK3172 | Without TCXO | No IPEX | EU433 | 301026 |
| RAK3172-47-SM-NI  | RAK3172 | Without TCXO | No IPEX | CN470 | 302033 |
| RAK3172-T-8-SM-NI | RAK3172-T  | With ±2.5 ppm TCXO | No IPEX | 8XX MHz for RU864/IN865/EU868  | 305054 |
| RAK3172-T-9-SM-NI | RAK3172-T  | With ±2.5 ppm TCXO | No IPEX | 9XX MHz for US915/AU915/KR920/AS923 | 306051 |
| RAK3172-T-9-SM-NI | RAK3172-T  | With ±2.5 ppm TCXO | No IPEX | AS923-1 Japan | 309054 |
| RAK3172-T-43-SM-NI | RAK3172-T  | With ±2.5 ppm TCXO | No IPEX | EU433 | 301029 |
| RAK3172-T-47-SM-NI | RAK3172-T  | With ±2.5 ppm TCXO | No IPEX | CN470 | 302037 |
| RAK3172-TE-8-SM-NI | RAK3172-TE | With ±0.5 ppm TCXO | No IPEX | 8XX MHz for RU864/IN865/EU868  | 305058 |
| RAK3172-TE-9-SM-NI | RAK3172-TE | With ±0.5 ppm TCXO | No IPEX | 9XX MHz for US915/AU915/KR920/AS923 | 306055 |
| RAK3172-TE-9-SM-NI | RAK3172-TE | With ±0.5 ppm TCXO | No IPEX | AS923-1 Japan | 309057 |
| RAK3172-TE-43-SM-NI | RAK3172-TE | With ±0.5 ppm TCXO | No IPEX | EU433 | - |
| RAK3172-TE-47-SM-NI | RAK3172-TE | With ±0.5 ppm TCXO | No IPEX | CN470 | - |
| RAK3172-8-SM-I | RAK3172 | Without TCXO | With IPEX | 8XX MHz for RU864/IN865/EU868  | 305045 |
| RAK3172-9-SM-I | RAK3172 | Without TCXO | With IPEX | 9XX MHz for US915/AU915/KR920/AS923 | 306042 |
| RAK3172-9-SM-I | RAK3172 | Without TCXO | With IPEX | AS923-1 Japan | 309045 |
| RAK3172-43-SM-I | RAK3172 | Without TCXO | With IPEX | EU433 | 301025 |
| RAK3172-47-SM-I | RAK3172 | Without TCXO | With IPEX | CN470 | 302032 |
| RAK3172-T-8-SM-I  | RAK3172-T  | With ±2.5 ppm TCXO | With IPEX | 8XX MHz for RU864/IN865/EU868  | 305055 |
| RAK3172-T-9-SM-I  | RAK3172-T  | With ±2.5 ppm TCXO | With IPEX | 9XX MHz for US915/AU915/KR920/AS923 | 306052 |
| RAK3172-T-9-SM-I  | RAK3172-T  | With ±2.5 ppm TCXO | With IPEX | AS923-1 Japan | 309055 |
| RAK3172-T-43-SM-I | RAK3172-T  | With ±2.5 ppm TCXO | With IPEX | EU433 | 301030 |
| RAK3172-T-47-SM-I | RAK3172-T  | With ±2.5 ppm TCXO | With IPEX | CN470 | 302038 |
| RAK3172-TE-8-SM-I | RAK3172-TE | With ±0.5 ppm TCXO | With IPEX | 8XX MHz for RU864/IN865/EU868  | 305057 |
| RAK3172-TE-9-SM-I | RAK3172-TE | With ±0.5 ppm TCXO | With IPEX | 9XX MHz for US915/AU915/KR920/AS923 | 306054 |
| RAK3172-TE-9-SM-I | RAK3172-TE | With ±0.5 ppm TCXO | With IPEX | AS923-1 Japan | 309056 |
| RAK3172-TE-43-SM-I | RAK3172-TE | With ±0.5 ppm TCXO | With IPEX | EU433 | - |
| RAK3172-TE-47-SM-I | RAK3172-TE | With ±0.5 ppm TCXO | With IPEX | CN470 | - |

## Certification

*   ANATEL Certification
*   CE Certification
*   FCC Certification
*   ISED Certification
*   JRL Certification
*   KC Certification
*   LoRaWAN Certification
*   RCM Certification
*   REACH Certification
*   RoHS Certification
*   RSM Certification
*   UKCA Certification
*   WPC Certification

**Note**
For CE and FCC certifications we provide an AT command guide.
You can find it in our RUI3 documentation or get it from our Download Center.

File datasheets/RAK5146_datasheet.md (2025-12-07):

# RAK5146 LoRaWAN Gateway Module Datasheet | Specs & Features[1]

## Overview[1]
The RAK5146 is an LPWAN Concentrator Module in a mini-PCIe form factor, featuring the Semtech SX1303 and SX126X for the Listen Before Talk (LBT) feature. It allows seamless integration into existing routers or other network equipment with LPWAN Gateway capabilities. This module can be used with any embedded platform that has an available mini-PCIe slot with SPI/USB connectivity and includes an onboard ZOE-M8Q GPS chip.[1]

This concentrator offers a comprehensive and cost-efficient gateway solution, providing up to 10 programmable parallel demodulation paths, an 8 x 8 channel LoRa packet detector, 8 x SF5-SF12 LoRa demodulators, and 8 x SF5-SF10 LoRa demodulators. It can detect an uninterrupted combination of packets at 8 different spreading factors and 10 channels, and continuously demodulate up to 16 packets, making it suitable for smart metering fixed networks and Internet-of-Things (IoT) applications.[1]

## Product Features[1]
*   Designed based on Mini PCI-e form factor[1]
*   SX1303 baseband processor emulates 8 x 8 channels LoRa packet detectors, 8x SF5-SF12 LoRa demodulators, 8x SF5-SF10 LoRa demodulators, one 125/250/500 kHz high-speed LoRa demodulator, and one (G)FSK demodulator[1]
*   3.3 V Mini PCI-e, compatible with 3G/LTE card of Mini PCI-e type[1]
*   Tx power up to 27 dBm, Rx sensitivity down to -139 dBm @ SF12, BW 125 kHz[1]
*   Supports global license-free frequency band: EU868, EU433, RU864, CN470, US915, AS923, AU915, KR920, and IN865[1]
*   Supports optional SPI/USB interfaces.[1]
*   Listen Before Talk[1]
*   Fine Timestamp[1]
*   Built-in ZOE-M8Q GPS module[1]

## Specifications[1]

### Overview[1]
The overview shows the top and back views of the RAK5146 board and presents a block diagram.[1]

#### Board Overview[1]
The RAK5146 is a compact LPWAN Gateway Module suitable for integration in systems with mass and size constraints. It is designed with the PCI Express Mini Card form factor, allowing it to be part of products complying with the standard, provided they allow cards with a thickness of at least 5.5 mm. The board has two UFL interfaces for the LoRa and GNSS antennas and a standard 52-pin connector (mPCIe).[1]
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

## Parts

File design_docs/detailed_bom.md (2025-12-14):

# Detailed Bill of Materials (Current Plan)

This BOM reflects the *current* architecture: **USB‑C + STM32F042 bridge** for development (power + console + CMSIS‑DAP SWD / UART bootloader), **JST 2‑wire battery connector** for field deployment, and a **24‑pin FPC connector** for the e‑paper cable.

## 1. Core Electronics (PCBA)

| Block | Part | Manufacturer | Part Number | Notes / Datasheet |
|---|---|---|---|---|
| MCU + LoRa | RAK3172 module | RAKwireless | RAK3172 | `datasheets/RAK3172_C19723904.pdf` |
| Load cell ADC | HX711 | Avia | HX711 | `datasheets/hx711.pdf` |
| E‑paper display | GDEY0213B74 | Good Display | GDEY0213B74 | `datasheets/GDEY0213B74.pdf` |
| E‑paper connector | 24‑pin 0.5 mm FPC | TE Connectivity | 2‑1734839‑4 | `datasheets/TE_2-1734839-4_C3168150.pdf` |
| USB connector | USB‑C receptacle (dev power/console/boot) | HRO | TYPE‑C‑31‑M‑12 | `datasheets/HRO_TYPE-C-31-M-12_C165948.pdf` |
| USB bridge | STM32F042F6P6 (USB CDC + CMSIS‑DAP SWD) | ST | STM32F042F6P6 | `https://www.st.com/resource/en/datasheet/stm32f042f6.pdf` |
| USB LDO | 3.3 V LDO | Microchip | MIC5504‑3.3YM5 | `datasheets/MIC5504.pdf` |
| Battery boost | boost converter | TI | TPS61220DCKR | `datasheets/TPS61220.pdf` |
| Rail ORing | Schottky diode | onsemi (or equiv) | SS14 | `datasheets/SS14.pdf` (x2) |
| Battery connector | JST‑PH 2‑pin (field battery harness) | JST | S2B‑PH‑SM4‑TB | `datasheets/JST_S2B-PH-SM4-TB_C295747.pdf` |
| RF connector | u.FL / I‑PEX | Hirose | U.FL‑R‑SMT‑1 | `datasheets/U.FL-R-SMT-1_C88373.pdf` |
| HX power gate | P‑MOSFET | Vishay | SI2301CDS | `datasheets/SI2301CDS-T1-GE3_C10487.pdf` |
| Buzzer driver | N‑MOSFET | onsemi (or equiv) | 2N7002 | `datasheets/2N7002LT1G_C16338.pdf` |
| Buzzer | magnetic SMD | CUI | CMT‑8504‑100‑SMT | (KiCad footprint: `Buzzer_Beeper:MagneticBuzzer_CUI_CMT-8504-100-SMT`) |
| Button | tactile switch | C&K | PTS645 | `datasheets/pts645.pdf` |
| LED | 0603 red | generic | LED 0603 red | (assembly‑friendly footprint) |
| Passives | R/C/L | generic | 0603 | values per schematic |

## 2. E‑Paper HV Booster (Required for SSD1680)

The SSD1680 requires an external booster/regulator application circuit (inductor + MOSFET + diodes + capacitors) for the HV rails. Reference:
- `datasheets/SSD1680.pdf` (Section 6.3 “Booster & Regulator”)
- `datasheets/GDEY0213B74.pdf` (module reference circuit)

Recommended parts (package choices are driven by availability and placement near the FPC connector):
- **Inductor:** 47 µH (≥500 mA), SMD (size TBD; avoid 0603 for this value/current)
- **MOSFET:** Si1308EDL (SOT‑323)
- **Schottky diodes:** MBR0530 (SOD‑123) ×3
- **Sense resistor:** 2.2 Ω
- **Caps:** 4.7 µF / 25 V and 1 µF / 25 V (multiple, per reference circuit)

## 3. Mechanical / Off‑Board
- **Battery pack:** housed in a separate battery case; connects to the PCB via JST‑PH 2‑wire cable.
- **Display module:** mounted in the enclosure front; connects to the PCB via the 24‑pin FPC cable.

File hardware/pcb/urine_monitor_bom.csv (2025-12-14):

Refs | Value | Footprint | Qty | DNP
BT1 | BAT_JST | Connector_JST:JST_PH_S2B-PH-SM4-TB_1x02-1MP_P2.00mm_Horizontal | 1
BZ1 | Buzzer | Buzzer_Beeper:MagneticBuzzer_CUI_CMT-8504-100-SMT | 1
C1 | 10uF | Capacitor_SMD:C_0603_1608Metric | 1
C2 | 0.1uF | Capacitor_SMD:C_0603_1608Metric | 1
C3 | 10uF | Capacitor_SMD:C_0603_1608Metric | 1
C4 | 0.1uF | Capacitor_SMD:C_0603_1608Metric | 1
D1 | RED | LED_SMD:LED_0603_1608Metric | 1
D2 | SS14 | Diode_SMD:D_SOD-123 | 1
D3 | SS14 | Diode_SMD:D_SOD-123 | 1
J1 | LoadCell | Connector_PinHeader_2.54mm:PinHeader_1x04_P2.54mm_Vertical | 1
J2 | EInk_FPC | Connector_FFC-FPC:TE_2-1734839-4_1x24-1MP_P0.5mm_Horizontal | 1
J3 | USB-C_Dev | Connector_USB:USB_C_Receptacle_HRO_TYPE-C-31-M-12 | 1
J4 | I2C+BOOT0+PWR | Connector_PinHeader_2.54mm:PinHeader_1x05_P2.54mm_Vertical | 1
J5 | Antenna_UFL | Connector_Coaxial:U.FL_Hirose_U.FL-R-SMT-1_Vertical | 1
L1 | 4.7uH | Inductor_SMD:L_0603_1608Metric | 1
Q1 | SI2301 | Package_TO_SOT_SMD:SOT-23 | 1
Q2 | 2N7002 | Package_TO_SOT_SMD:SOT-23 | 1
R1 | 1M | Resistor_SMD:R_0603_1608Metric | 1
R2 | 1M | Resistor_SMD:R_0603_1608Metric | 1
R3 | 100k | Resistor_SMD:R_0603_1608Metric | 1
R4 | 1k | Resistor_SMD:R_0603_1608Metric | 1
R5 | 5k1 | Resistor_SMD:R_0603_1608Metric | 1
R6 | 5k1 | Resistor_SMD:R_0603_1608Metric | 1
SW1 | USER_BTN | Button_Switch_SMD:SW_SPST_TL3342 | 1
U1 | RAK3172 | RF_Module:RAK3172 | 1
U2 | HX711 | Package_SO:SOIC-16_3.9x9.9mm_P1.27mm | 1
U3 | TPS61220 | Package_TO_SOT_SMD:SOT-363_SC-70-6 | 1
U4 | MIC5504-3.3 | Package_TO_SOT_SMD:SOT-23-5 | 1
U5 | STM32F042F6P6 (USB CDC + CMSIS-DAP) | Package_SO:TSSOP-20_4.4x6.5mm_P0.65mm | 1

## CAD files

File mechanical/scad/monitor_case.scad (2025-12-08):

// Urine Monitor Case & Assembly
// Dimensions: mm

// --- Parameters ---

// PCB Dimensions (from KiCad Edge.Cuts)
pcb_w = 64;
pcb_h = 100;
pcb_th = 1.6;

// Clearance
clearance = 1.0; 

// Case Dimensions
wall_th = 2.5;
case_w = pcb_w + 2*clearance + 2*wall_th; // approx 71mm
case_h = pcb_h + 2*clearance + 2*wall_th + 15; // Extra space for hook mech at bottom
case_d = 35;
fillet_r = 4;

// Display (GDEY0213B74 2.13" E-Ink)
disp_w = 48.5; 
disp_h = 23.7; 
disp_pcb_w = 59.2; // Module PCB width
disp_pcb_h = 29.2;
disp_y_offset = 20;

// Components
batt_dia = 14.5;
batt_len = 50.5;

// Hook / Sensor
sensor_dia = 15;
sensor_h = 5;

// View Control
show_case_front = 1;
show_case_back = 1;
show_pcb = 1;
show_internals = 1;
exploded = 20; // Distance to separate parts for view

$fn = 50;

// --- Components Modules ---

module pcb_board() {
    color("green") 
        difference() {
            cube([pcb_w, pcb_h, pcb_th], center=true);
            // Mounting holes
            for(x=[-30, 30]) for(y=[-48, 48])
                translate([x, y, -1]) cylinder(d=3.2, h=5);
        }
}

module display_module() {
    // Glass
    color("white") translate([0, disp_y_offset, 1])
        cube([disp_w, disp_h, 1.2], center=true);
    // Ribbon / Driver area
    color("gray") translate([0, disp_y_offset - 15, 0.5])
        cube([30, 10, 1], center=true);
}

module battery_pack() {
    // 2x AA Holder
    color("black") translate([0, 0, 0])
        cube([batt_dia*2 + 4, batt_len + 4, batt_dia/2 + 2], center=true);
    // Batteries
    color("blue") translate([-batt_dia/2 - 1, 0, 2])
        rotate([90, 0, 0]) cylinder(d=batt_dia, h=batt_len, center=true);
    color("blue") translate([batt_dia/2 + 1, 0, 2])
        rotate([90, 0, 0]) cylinder(d=batt_dia, h=batt_len, center=true);
}

module load_cell_sensor() {
    color("silver") cylinder(d=sensor_dia, h=sensor_h);
    color("red") translate([0,0,sensor_h]) cylinder(d=4, h=2); // Button nip
}

module hook_bridge() {
    color("orange") {
        difference() {
            union() {
                // Cross bar
                translate([0, 0, 5]) cube([30, 10, 6], center=true);
                // Vertical legs down to hook
                translate([0, -5, -5]) cube([10, 5, 20], center=true);
            }
        }
        // Hook
        translate([0, -5, -15]) rotate([0, 90, 0]) cylinder(d=4, h=10, center=true);
    }
}

// --- Case Modules ---

module rounded_rect(w, h, d, r) {
    hull() {
        translate([-w/2+r, -h/2+r, 0]) cylinder(r=r, h=d);
        translate([w/2-r, -h/2+r, 0]) cylinder(r=r, h=d);
        translate([-w/2+r, h/2-r, 0]) cylinder(r=r, h=d);
        translate([w/2-r, h/2-r, 0]) cylinder(r=r, h=d);
    }
}

module front_shell() {
    color("whitesmoke", 0.8) 
    difference() {
        // Body
        rounded_rect(case_w, case_h, case_d/2, fillet_r);
        
        // Interior hollow
        translate([0, 0, wall_th])
            rounded_rect(case_w - 2*wall_th, case_h - 2*wall_th, case_d/2, fillet_r);
            
        // Window Cutout
        translate([0, disp_y_offset, -1])
            cube([disp_w, disp_h, wall_th+2], center=true);
            
        // Screw Bosses Recess (from inside)
        // ... omitted for brevity, implied standard boss
    }
    
    // Tube Clip (External feature)
    translate([case_w/2, -20, case_d/4]) rotate([0, 90, 0])
        difference() {
            cylinder(d=15, h=10); // Holder body
            translate([0,0,-1]) cylinder(d=6, h=12); // Tube hole
            translate([3, 0, -1]) cube([6, 15, 12], center=true); // Side opening
        }
}

module back_shell() {
    color("whitesmoke", 0.8)
    difference() {
        rounded_rect(case_w, case_h, case_d/2, fillet_r);
        
        translate([0, 0, wall_th])
            rounded_rect(case_w - 2*wall_th, case_h - 2*wall_th, case_d/2, fillet_r);
            
        // Battery Door Cutout (simplified)
        translate([0, -10, -1])
             rounded_rect(35, 55, wall_th+2, 2);
    }
    
    // Clamp Mount
    translate([0, 20, -5]) cube([20, 30, 5], center=true);
}


// --- Assembly ---

// Z-Stacking order:
// Front Shell -> Display -> PCB -> Batteries -> Back Shell

// 1. Front Shell
if (show_case_front)
    translate([0, 0, exploded*2 + 10]) rotate([180, 0, 0]) front_shell();

// 2. Internals
if (show_internals) {
    translate([0, 0, 0]) {
        // Display
        translate([0, 0, 3]) display_module();
        
        // PCB
        if (show_pcb) translate([0, 0, 0]) pcb_board();
        
        // Batteries (on back of PCB)
        translate([0, -10, -batt_dia/2 - 2]) battery_pack();
        
        // Sensor (Bottom of PCB)
        translate([0, -pcb_h/2 + 10, -3]) load_cell_sensor();
        
        // Hook Mechanism
        translate([0, -pcb_h/2 + 10, -10]) hook_bridge();
    }
}

// 3. Back Shell
if (show_case_back)
    translate([0, 0, -exploded - 15]) rotate([180, 0, 0]) scale([1, 1, -1]) back_shell();

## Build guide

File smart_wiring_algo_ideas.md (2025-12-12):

````markdown
# Advanced Auto-Wiring Algorithms in EDA Routers  
_Generic principles for PCB / FPGA / ASIC routing_

This document summarizes the core algorithms and techniques behind **“smart” auto wiring** in EDA tools: how routers connect nets while:

- Never routing **through** placed chips or keep-out regions.
- Avoiding messy crossings and congestion hotspots.
- Respecting timing, signal-integrity, and manufacturability constraints.

The focus is on **generic algorithmic structure** that applies across PCB, FPGA and ASIC flows.

---

## 1. Problem Model

At its core, auto wiring (routing) solves a constrained path-finding problem on a geometric domain:

- **Inputs**
  - Set of **pins** grouped into **nets**.
  - **Obstacles**: components, macros, keep-out regions, power planes.
  - **Resources**: routing layers, tracks or free space, via rules.
  - **Constraints**: design rules (DRC), timing, SI/EMI, power, cost weights.

- **Outputs**
  - For each net, a set of **wires + vias** forming a valid connection.
  - No DRC violations, no routing through obstacles, and acceptable PPA (power, performance, area / board area).

Most production routers decompose this into:

1. **Global Routing**
   - Coarse grid / tiles.
   - Decide **which regions and layers** each net will use.
   - Optimize congestion, wirelength, via count.

2. **Detailed Routing**
   - Fine-grained geometry.
   - Generate exact wire/via shapes that obey DRC and follow global guides.

This 2-level decomposition is universal across modern VLSI and PCB routers. :contentReference[oaicite:0]{index=0}  

---

## 2. Geometry Models: Grid vs Shape

### 2.1 Grid-Based (Gridded) Models

- Layout is discretized into a **grid graph**.
- Nodes: potential routing points; edges: allowable segments.
- Obstacles (chips, keep-outs) become **blocked nodes/edges**.
- Routing becomes **graph search** + resource allocation.

Pros:
- Simple implementation.
- Easy to integrate with classical shortest-path / maze algorithms.

Cons:
- Resolution limited by grid pitch.
- Geometry approximated; may waste space or miss tight opportunities.

Grid-based is standard for **global routing** and many detailed routers (e.g., TritonRoute’s A*-based worker). :contentReference[oaicite:1]{index=1}  

### 2.2 Shape-Based (Gridless) Models

- Wires and obstacles stored as **polygons / rectangles** in a shape database.
- Routing space computed as **free rectangles** or polygons.
- Path search “floods” free space, dynamically updating shapes and checking parasitics. :contentReference[oaicite:2]{index=2}  

Pros:
- Better packing efficiency, important for **analog / RF / custom**.
- Parasitic-driven path selection in real time.

Cons:
- More complex geometry checks.
- Harder to parallelize.

Many custom/analog routers are now **shape-based detailed routers**, sitting on top of a grid-based global router.

---

## 3. Core Routing Algorithms

### 3.1 Maze Routing (Lee / A*)

Classical **maze routing** sees the layout grid as a maze:

- **Lee’s Algorithm** (BFS):
  - Wavefront expansion from source until target reached.
  - Always finds a shortest path (if one exists) in unweighted grids. :contentReference[oaicite:3]{index=3}  
- **A\***:
  - Adds heuristic (e.g., Manhattan or Chebyshev distance) to guide search.
  - Much faster than pure BFS, especially with good heuristics. :contentReference[oaicite:4]{index=4}  

Generic cost for each edge (segment):

```text
cost = w_len * length
     + w_via * via_penalty
     + w_cong * congestion_cost
     + w_timing * timing_cost
     + w_SI * crosstalk_risk
````

Pseudo-A* skeleton used inside many detailed routers:

```pseudo
function route_net_Astar(net, grid, cost_fn):
    open_set  = min_heap()
    push(open_set, (0, src_node))
    g[src_node] = 0
    parent = {}

    while open_set not empty:
        (f, u) = pop_min(open_set)
        if u == dst_node:
            return reconstruct_path(parent, u)

        for each neighbor v of u:
            if v is blocked (obstacle or DRC):
                continue
            tentative_g = g[u] + cost_fn(u, v)
            if tentative_g < g[v]:
                g[v] = tentative_g
                parent[v] = u
                h = heuristic(v, dst_node)   # e.g. Manhattan
                f = g[v] + h
                push_or_update(open_set, (f, v))

    return FAIL  # net unroutable within current resources
```

The **“smart” behavior** comes from a good `cost_fn` and a good `heuristic`, not from the search skeleton itself.

---

### 3.2 Steiner Trees & Obstacle-Avoidance

For multi-pin nets, routers often:

1. Build an **obstacle-aware Steiner tree** in a coarse model.
2. Route tree edges with maze routing.

Recent work proposes **rule-based obstacle-avoiding rectilinear Steiner minimal trees (OARSMT)** to avoid obstacles *early*, then uses sparse maze routing to avoid violations and overflow. ([arXiv][1])

Key points:

* Obstacles (chips, IP blocks, slots) are treated as **hard keep-out** nodes in the topology.
* The Steiner tree algorithm is modified to:

  * Prefer branches that skirt around obstacles with minimal wirelength increase.
  * Avoid creating branches that force later detours and via spikes.

This is exactly what prevents **“wires crossing chips”** at the global level.

---

### 3.3 Rip-Up and Reroute / Negotiation-Based Routing

Routing all nets at once leads to conflicts. Modern routers use **iterative negotiation**:

1. **Initial pass**:

   * Route nets one-by-one (often in a heuristic order) with simple costs.
   * Some resources become overused (overflow).

2. **Congestion analysis**:

   * For each edge/tile, compute usage vs capacity.
   * Congested edges get **penalty cost** increased.

3. **Rip-up & reroute loops**:

   * Select congested nets.
   * Rip up their routes.
   * Reroute them using updated congestion costs.

4. **Termination**:

   * Stop when no overflow or when improvement plateaus.

Dynamic congestion penalties and routing order are the heart of negotiation-based routers (e.g., DpRouter, ISPD contest winners). ([UCLA Electrical and Computer Engineering][2])

This **negotiation** is what gradually untangles messy crossings and spreads wires to less congested regions.

---

## 4. Constraint-Driven “Smartness”

The same search skeleton can support many “smart” behaviors by embedding more physics into the **cost model**.

### 4.1 Timing-Driven Routing

* Critical nets get:

  * Higher weight on **delay**, lower weight on wirelength.
  * Prefer shorter paths, fewer vias, thicker / top-layer routes.
* Non-critical nets:

  * Can detour to relieve congestion.

Timing-driven costs use estimates from **pre-routing timing prediction** or ML-based slack predictors. ([arXiv][3])

### 4.2 Signal Integrity & EMI-Aware Routing

* Cost terms penalize:

  * Parallel long runs between aggressor/victim nets.
  * Routing near noisy blocks (DC-DC, clock trees, high-speed links).
  * Excessive layer changes (via stubs).

RL and AI-enhanced routers have been proposed that explicitly consider crosstalk regions and vias to minimize SI issues. ([ResearchGate][4])

### 4.3 Power / Thermal / Reliability

Routers can:

* Prefer wider, shorter paths for high-current nets.
* Avoid thermal hotspots and E-field concentration regions.
* Reduce via stacks and stressed geometries.

These are baked into `cost_fn` and possibly into net ordering.

---

## 5. Net Ordering, Layer Assignment, and Batching

Even with a perfect inner router, **order matters**:

* Early nets have more freedom; late nets get squeezed.
* Poor net ordering creates chaotic crossing patterns.

Modern work uses:

* **Dynamic pattern routing / batching**:

  * Group nets that interact strongly (same region, layer competition).
  * Route these jointly or in carefully chosen sequences. ([UCLA Electrical and Computer Engineering][2])
* **ML-based ordering**:

  * Train models to predict an ordering of nets (and layer assignment) that minimizes congestion and via count. ([Nature][5])

This is one of the simplest yet high-impact levers to prevent “spaghetti routing.”

---

## 6. Detailed Routing and Shape-Based Cleanup

Once global routing and guides exist:

1. **Pin Access Generation**

   * For each pin, compute legal access points on layers.
   * Avoid overlapping obstacles and macros.

2. **Track-Based / Shape-Based Detailed Routing**

   * Within each global tile or “window,” the router:

     * Builds local grid or free-space rectangles.
     * Runs A* / maze with full DRC checks (spacing, enclosure, etc.).
   * Uses local rip-up/reroute to fix violations.

3. **Post-Route Optimization**

   * Shortening and straightening detours.
   * Replacing zig-zags with clean lines where resources free up.
   * Swapping layers or via locations to reduce coupling.

Shape-based routers integrate **real-time RC extraction** with path exploring, so they can reject paths that are DRC-clean but parasitic-terrible. ([EE Times][6])

---

## 7. Reinforcement Learning and Generative Models

Recent arXiv work goes beyond hand-tuned heuristics:

### 7.1 RL Global / Detailed Routing

* Treat routing as an **RL environment**:

  * **State**: partial layout, congestion map, current net segments.
  * **Action**: choose the next segment direction / layer / via.
  * **Reward**: negative wirelength, penalties for DRC, overflow, vias, timing violations.

Deep Q-Network (DQN) and policy-gradient approaches have shown improved results over classical A* in some settings. ([Carnegie Mellon University VDE ][7])

### 7.2 Generative / GAN-Assisted Global Routing

* Use GANs or generative models to **predict routability and congestion maps** or even propose routing patterns.
* Routers then refine these suggestions with classical algorithms. ([arXiv][8])

The typical pattern is **hybrid**:

* ML predicts *where* to route or *how* to order.
* Classical A* / maze + negotiation still does the hard DRC-exact work.

---

## 8. Ensuring “No Wires Crossing Chips” in Practice

Putting it all together, a robust “smart auto wiring” stack enforces:

1. **Obstacle Modeling**

   * Components, macro blocks, BGAs, mounting holes, forbidden regions → obstacles in both global and detailed models.
   * Any grid nodes or shapes overlapping these areas are permanently blocked.

2. **Guide-Respecting Routers**

   * Global routing creates **channels around obstacles**, never through them.
   * Detailed routers are constrained to these guides unless rip-up/reroute explicitly allows deviation.

3. **Congestion-Aware Negotiation**

   * If wires form messy crossings in one corridor, congestion cost spikes.
   * Rip-up/reroute redistributes nets to alternative corridors or layers.

4. **Net Ordering & Priority**

   * Critical nets routed first with wide, clean paths.
   * Bulk low-priority nets fill in remaining space, often allowed to bend more.

5. **Post-Route Cleanup**

   * Local shape optimizations remove unnecessary jogs and crossings.
   * DRC + parasitic checks ensure the final picture is both **clean** and **electrically sane**.

---

## 9. Practical Design Notes for Implementers

If you want to implement a **minimal but non-toy smart router** (for PCB/FPGA/ASIC):

1. Start with a **grid-based global router**:

   * Graph model with capacities, obstacles, and a basic A* + rip-up/reroute loop.
2. Add **multi-objective costs** in A*:

   * `length`, `via`, `congestion`; later add timing/SI terms.
3. Implement **net ordering + batching**:

   * Simple heuristics (critical first, long nets first) pay off quickly.
4. Add a **window-based detailed router**:

   * A* in local boxes, checking DRC (clearances, width, via rules).
5. Layer in **ML assistance** later:

   * Use ML to predict congestion, net ordering, or cost weights rather than to replace the entire router.

---

## 10. Selected References

* Global/detailed routing tutorials and models: ([NTU EECS][9])
* A*-based detailed routing (TritonRoute, open-source): ([VLSI CAD Laboratory][10])
* Obstacle-aware global routing with OARSMT trees: ([arXiv][1])
* Shape-based routing and parasitic-aware flows: ([EE Times][6])
* PCB routing algorithms and region-aware methods: ([Iowa State University Digital Repository][11])
* Deep RL global routing and follow-ups: ([Carnegie Mellon University VDE ][7])
* ML-based routing surveys and applications in EDA: ([ACM Digital Library][12])
* GAN-assisted and batching-oriented global routing: ([arXiv][13])

---

```
::contentReference[oaicite:22]{index=22}
```

[1]: https://arxiv.org/abs/2503.07268?utm_source=chatgpt.com "A High Efficient and Scalable Obstacle-Avoiding VLSI Global Routing Flow"
[2]: https://eda.ee.ucla.edu/pub/c95.pdf?utm_source=chatgpt.com "DpRouter: A Fast and Accurate Dynamic-Pattern-Based ..."
[3]: https://arxiv.org/abs/2501.07564?utm_source=chatgpt.com "E2ESlack: An End-to-End Graph-Based Framework for Pre-Routing Slack Prediction"
[4]: https://www.researchgate.net/publication/347449313_Reinforcement_Learning-based_Auto-router_considering_Signal_Integrity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 "Reinforcement Learning-based Auto-router considering ..."
[5]: https://www.nature.com/articles/s41598-024-82226-9.pdf?utm_source=chatgpt.com "Machine learning optimal ordering in global routing ..."
[6]: https://www.eetimes.com/automatic-shape-based-routing-to-achieve-parasitic-constraint-closure-in-custom-design/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 "Automatic shape-based routing to achieve parasitic ..."
[7]: https://vdel.me.cmu.edu/vdelresource/publications/2020jmdglobalrouting/paper.pdf?utm_source=chatgpt.com "a deep reinforcement learning approach for global routing"
[8]: https://arxiv.org/abs/2511.17665?utm_source=chatgpt.com "GAN-Assisted Scalable and Efficient Global Routing ..."
[9]: https://cc.ee.ntu.edu.tw/~ywchang/Courses/PD_Source/EDA_routing.pdf?utm_source=chatgpt.com "Global and detailed routing"
[10]: https://vlsicad.ucsd.edu/Publications/Journals/j133.pdf?utm_source=chatgpt.com "TritonRoute: The Open Source Detailed Router"
[11]: https://dr.lib.iastate.edu/bitstreams/baa06fe6-541d-4f4a-888d-94f3083cd518/download?utm_source=chatgpt.com "Towards automated PCB routing"
[12]: https://dl.acm.org/doi/10.1016/j.vlsi.2022.05.003?utm_source=chatgpt.com "A survey on machine learning-based routing for VLSI ..."
[13]: https://arxiv.org/html/2511.17665v1?utm_source=chatgpt.com "GAN-Assisted Scalable and Efficient Global Routing ..."

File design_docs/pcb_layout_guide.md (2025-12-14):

# PCB Design Guide & Layout Guidelines

## 1. Stackup & Specifications
*   **Layers:** 2-Layer Standard FR4 (Cost effective).
*   **Thickness:** 1.6mm.
*   **Copper:** 1oz (35um).
*   **Finish:** HASL (Lead-free) or ENIG (for better pad flatness on RAK3172).

## 2. Component Placement
This project is designed around **edge‑anchored connectors** and **functional grouping** to keep routing short and predictable.

1. **USB‑C (Dev) edge (thermal + mechanical priority):**
   - Place the **USB‑C receptacle centered on a short edge** (mechanical alignment + cable strain relief).
   - Place the **STM32F042 debug bridge + its decoupling** close to the USB‑C D+/D‑ pins (USB CDC + CMSIS‑DAP).
   - Place the **MIC5504 LDO** close to VBUS input; leave copper for heat spreading; keep the USB power area away from HX711 analog inputs.

2. **Battery (Field) connector:**
   - Use a **2‑wire JST‑PH** connector (`BAT`, `GND`).
   - Place it on the bottom edge offset from USB so the harness exits downward without crowding the dev connector.

3. **RF section:**
   - Place the **RAK3172** near the top edge.
   - Place the **u.FL** connector very close to the module RF pin; keep the 50 Ω feed short and straight.

4. **Analog section (HX711):**
   - Place HX711 and its local decoupling **right next to** the load cell connector.
   - Keep digital/HV switching away from the bridge inputs.

5. **Display section (FPC + HV booster):**
   - Place the **24‑pin FPC connector on a board edge** to simplify cable routing to the display.
   - Place the **SSD1680 booster circuit and HV capacitors** tightly around the connector pins.
   - Keep this HV area away from the HX711 and RF feed.

Current auto-generated placement (60×80 mm rectangle) keeps USB‑C centered on the bottom short edge with the STM32F042 bridge + USB Schottky just above it, the JST battery at the lower‑left, HX711/load cell mid‑left, the FPC mid‑right, RAK3172 + u.FL near the top, and the buzzer away from the RF/debug corner.

## 3. Routing Guidelines

### A. RF Trace (Critical)
*   **Impedance:** The trace from RAK3172 pin `RF` to the IPEX connector must be **50 Ohms**.
*   **Calculation:** For 1.6mm FR4 (Er ~4.5), a 50-ohm microstrip trace is roughly **~2.8mm to 3.0mm wide**.
    *   *Tip:* Since this is wide, keep the trace very short (< 5mm) to minimize mismatch issues if you can't match the width perfectly.
*   **Grounding:** Place a solid Ground Pour on the Bottom Layer directly underneath the RF trace. Stitch with vias along the trace.

### B. Analog Signals (HX711)
*   **Differential Pairs:** Route `E+`/`E-` and `A+`/`A-` as differential pairs. Keep them parallel and close together.
*   **Isolation:** Surround these traces with Ground signals (Guard Traces) if possible.
*   **No Crossing:** Do NOT route digital signals (SCK/DT) under or over these analog lines.

### C. Power Routing
*   **VCC Trace:** Use at least 0.5mm width for main 3.3V lines.
*   **GND:** Use a "Star Ground" topology if possible, or a solid Ground Plane (Bottom Layer) for the entire board.
*   **Decoupling:** Place 0.1uF capacitors **immediately** next to the VCC pins of the RAK3172 and HX711.

### D. E-Ink Booster & High Voltage
*   **Switching Loop:** The connection between the Inductor (L1), MOSFET (Q1), and Diodes (D1-D3) switches at high frequency. Keep this loop **extremely small** to minimize EMI.
*   **High Voltage Caps:** The capacitors for VGH, VGL, VSH, VSL (+/-20V, +/-15V) must be rated for **25V** minimum.
*   **Placement:** Place these capacitors as close as possible to the FPC connector pins to stabilize the drive voltages.
*   **Isolation:** Keep these noisy switching signals away from the sensitive Analog (HX711) and RF sections.

## 4. Schematic Checklist
- [ ] **Reset:** Pull-up resistor (10k) on RAK3172 RST pin? (Module usually has internal, check datasheet).
- [ ] **Boot0 + Reset:** Provide a way to enter the STM32 ROM bootloader for UART flashing (BOOT0 strap + reset access).
- [ ] **Console/Debug:** Route UART2 + SWD to the STM32F042 bridge (USB CDC + CMSIS‑DAP) for logs/flashing.
- [ ] **Antenna:** IPEX connector (U.FL) footprint matches the part number.
- [ ] **Battery input:** JST‑PH 2‑wire connector; consider reverse‑polarity protection if needed.
- [ ] **E-Ink Config:** Verify **BS1** is tied to GND (4-Wire SPI).
- [ ] **Booster Ratings:** Verify Diodes/Caps are rated >25V (Logic is 3.3V, but Booster is 20V).

## 5. Fabrication Files (Gerber)
*   Export: Top Copper, Bottom Copper, Top Solder Mask, Bottom Solder Mask, Top Silkscreen, Bottom Silkscreen, Drill, Outline.
*   Silkscreen: Keep reference designators visible (`U*`, `R*`, `C*`, `J*`) with sane text size (e.g., 1.0mm height, 0.15mm stroke) and away from pads.

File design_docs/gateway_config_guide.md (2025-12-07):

# RAK7268V2 Gateway Configuration Guide
## Hospital Urine Bag Monitoring System

### 1. Objective
Configure the **RAK7268V2 WisGate Edge Lite 2** to act as a **Packet Forwarder**. It will receive LoRaWAN RF packets from the sensor nodes and forward them via Ethernet/Wi-Fi to the central **ChirpStack Network Server (LNS)**.

### 2. Physical Setup
1.  **Antenna:** Connect the LoRa Antenna to the **RP-SMA** connector (Labelled "LoRa").
2.  **Power:** Connect via **PoE (Ethernet Port)** OR **12V DC Adapter**.
3.  **Network:** Connect Ethernet cable to the hospital LAN (if using PoE/Ethernet).

### 3. Accessing the Web UI
1.  **Default Wi-Fi:** The gateway broadcasts an AP named `RAK7268_xxxx` (last 4 bytes of MAC).
2.  **Connect:** Join this Wi-Fi network (Password usually `rakwireless` or printed on the label).
3.  **Browser:** Open `http://192.168.230.1`.
4.  **Login:**
    *   User: `root`
    *   Password: `root` (Change this immediately upon first login!).

### 4. Network Configuration (Uplink/Backhaul)
Navigate to **Network -> WAN**.
*   **Protocol:** `DHCP Client` (typical for Hospital LAN) or `Static IP` (if required by IT).
*   **Failover (Important):**
    *   Go to **Network -> Interface**.
    *   Enable **"Uplink Backup"**.
    *   Primary: `Ethernet (eth0)`.
    *   Backup: `WWAN` (LTE) or `Wireless` (Wi-Fi Client) if available.
    *   *Ping Watchdog:* Enable. Host: `8.8.8.8` (or LNS IP). Interval: `60s`.

### 5. LoRaWAN Configuration
Navigate to **LoRa -> Configuration**.

#### A. Mode Selection
*   **Work Mode:** `Packet Forwarder`. (Do *not* select "Built-in Network Server" unless running a standalone demo).

#### B. Channel Plan
*   **Region:** Select matches your sensors (e.g., `US915` or `EU868`).
*   **Sub-band:**
    *   **US915:** Usually **Sub-band 2** (Channels 8-15 + 65). *Crucial: Must match Firmware setting.*
    *   **EU868:** Standard.

#### C. Server Setup (Pointing to ChirpStack)
*   **Protocol:** `Semtech UDPGW` (Standard) or `Basics Station` (More secure, TLS).
*   **Server Address:** IP address or Domain of your ChirpStack LNS (e.g., `192.168.10.50` or `lora.hospital-sys.com`).
*   **Uplink Port:** `1700` (Default for UDP).
*   **Downlink Port:** `1700`.

### 6. Verification
1.  Save & Apply.
2.  Go to **Status -> LoRa**.
3.  Check **"Packet Forwarder Status"**: Should be `Up` / `Connected`.
4.  Check **"Traffic"**: Trigger a sensor node (Press Button). You should see an entry in the "Traffic" log (even if it says "CRC Error" or "Bad MIC" initially, receiving RF proves hardware works).

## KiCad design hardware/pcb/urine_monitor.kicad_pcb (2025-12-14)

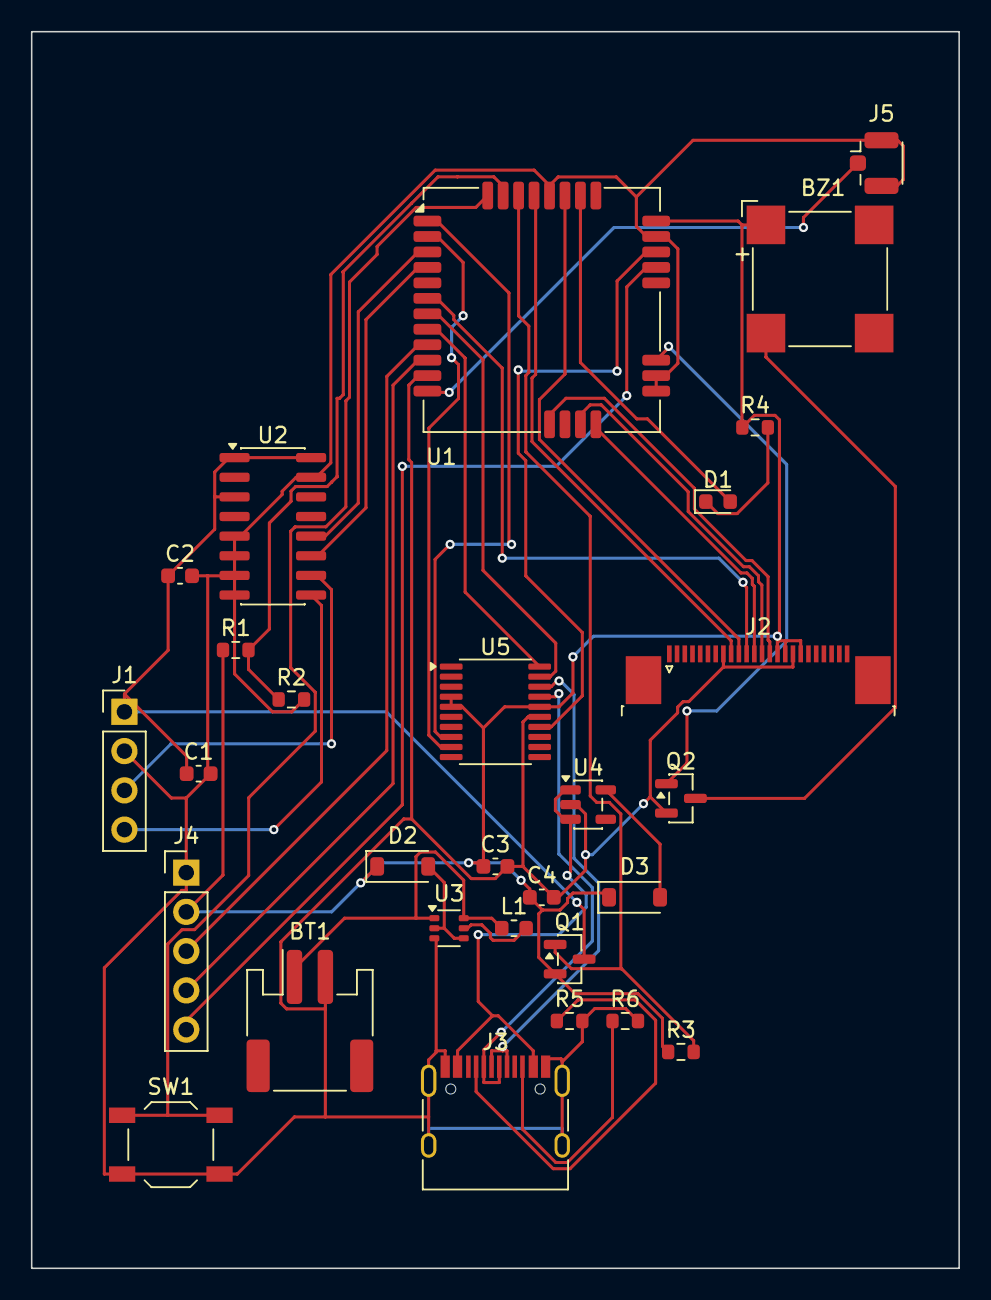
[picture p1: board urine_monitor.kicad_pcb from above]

Board: 2 copper layers, 60.0 x 80.0 mm, 29 parts (0 on the bottom side), 38 nets.

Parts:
BT1: BAT_JST; JST_PH_S2B-PH-SM4-TB_1x02-1MP_P2.00mm_Horizontal
BZ1: Buzzer; MagneticBuzzer_CUI_CMT-8504-100-SMT
C1, C3: 10uF; C_0603_1608Metric
C2, C4: 0.1uF; C_0603_1608Metric
D1: RED; LED_0603_1608Metric
D2, D3: SS14; D_SOD-123
J1: LoadCell; PinHeader_1x04_P2.54mm_Vertical
J2: EInk_FPC; TE_2-1734839-4_1x24-1MP_P0.5mm_Horizontal
J3: USB-C_Dev; USB_C_Receptacle_HRO_TYPE-C-31-M-12
J4: I2C+BOOT0+PWR; PinHeader_1x05_P2.54mm_Vertical
J5: Antenna_UFL; U.FL_Hirose_U.FL-R-SMT-1_Vertical
L1: 4.7uH; L_0603_1608Metric
Q1: SI2301; SOT-23
Q2: 2N7002; SOT-23
R1, R2: 1M; R_0603_1608Metric
R3: 100k; R_0603_1608Metric
R4: 1k; R_0603_1608Metric
R5, R6: 5k1; R_0603_1608Metric
SW1: USER_BTN; SW_SPST_TL3342
U1: RAK3172
U2: HX711; SOIC-16_3.9x9.9mm_P1.27mm
U3: TPS61220; SOT-363_SC-70-6
U4: MIC5504-3.3; SOT-23-5
U5: STM32F042F6P6 (USB CDC + CMSIS-DAP); TSSOP-20_4.4x6.5mm_P0.65mm

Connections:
BAT: BT1.1, L1.1, U3.1, U3.6
BAT_SENSE: R1.2, R2.1, U1.31
BOOT0: J4.5, U1.21
BTN_USER: SW1.1, U1.32
BUZZ_PWM: Q2.1, U1.19
BUZZ_SINK: BZ1.2, Q2.3
CC1: J3.A5, R5.1
CC2: J3.B5, R6.1
EINK_BUSY: J2.9, U1.29
EINK_CS: J2.12, U1.16
EINK_DC: J2.11, U1.6
EINK_MOSI: J2.14, U1.13
EINK_RST: J2.10, U1.27
EINK_SCK: J2.13, U1.15
GND: BT1.2, C1.2, C2.2, C3.2, C4.2, J1.2, J2.8, J2.17, J3.A1, J3.A12, J3.B1, J3.B12, J3.S1, J4.1, J5.2, Q2.2, R2.2, R5.2, R6.2, SW1.2, U1.11, U1.17, U1.18, U1.23, U1.28, U2.5, U2.6, U2.7, U2.8, U2.15, U3.3, U4.2, U5.15
HX711_DT: U1.3, U2.12
HX711_SCK: U1.4, U2.11
HX_GATE: Q1.1, R3.2, U1.30
HX_INB+: J1.3, U2.10
HX_INB-: J1.4, U2.9
HX_VCC: C1.1, C2.1, J1.1, Q1.3, U2.1, U2.3, U2.16
I2C_SCL: J4.3, U1.9
I2C_SDA: J4.4, U1.10
LED_NET: D1.1, R4.2
LED_STATUS: D1.2, U1.26
NRST: U1.22, U5.14
RF: J5.1, U1.12
SWCLK: U1.8, U5.20
SWDIO: U1.7, U5.19
U3_L: L1.2, U3.5
U3_OUT: D2.2, U3.2, U3.4
U4_OUT: D3.2, U4.5
UART2_RX: U1.1, U5.8
UART2_TX: U1.2, U5.9
USB_DM: J3.A7, J3.B7, U5.17
USB_DP: J3.A6, J3.B6, U5.18
VBUS: J3.A4, J3.A9, J3.B4, J3.B9, U4.1, U4.3
VCC: BZ1.1, C3.1, C4.1, D2.1, D3.1, J2.15, J2.16, J2.18, J4.2, Q1.2, R1.1, R3.1, R4.1, U1.24, U5.4, U5.5, U5.16

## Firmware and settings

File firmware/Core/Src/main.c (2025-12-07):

#include "main.h"
#include "app_lorawan.h"
#include "hx711_driver.h"
#include "epd_driver.h"

// Pin Definitions
#define PIN_POWER_GATE_PORT  GPIOB
#define PIN_POWER_GATE_PIN   GPIO_PIN_5

#define PIN_BUTTON_PORT      GPIOB
#define PIN_BUTTON_PIN       GPIO_PIN_3

#define PIN_BAT_ADC_PORT     GPIOB
#define PIN_BAT_ADC_PIN      GPIO_PIN_4

// Constants
#define CALIBRATION_FACTOR 100.0f // Placeholder
#define REPORT_INTERVAL 3600000 // 1 hour

// Global Flags
volatile bool evt_tare = false;
volatile bool evt_toggle_mode = false;
volatile uint32_t press_start_time = 0;
volatile bool button_pressed = false;

// Global Data
int32_t tare_offset = 0;
bool display_is_kg = false; // Default: mL (approx g)

void SystemClock_Config(void);
static void MX_GPIO_Init(void);
static void MX_ADC_Init(void);

// Button Interrupt Callback
void HAL_GPIO_EXTI_Callback(uint16_t GPIO_Pin) {
    if (GPIO_Pin == PIN_BUTTON_PIN) {
        // Simple logic: In a real HAL, we'd check edge
        // Assuming this is called on both edges for now, or just FALLING
        // For simplicity, let's assume we read the pin to determine state
        if (HAL_GPIO_ReadPin(PIN_BUTTON_PORT, PIN_BUTTON_PIN) == GPIO_PIN_RESET) {
            // Pressed (Active Low)
            press_start_time = HAL_GetTick();
            button_pressed = true;
        } else {
            // Released
            if (button_pressed) {
                uint32_t duration = HAL_GetTick() - press_start_time;
                if (duration > 50 && duration < 2000) {
                    evt_tare = true;
                } else if (duration >= 2000) {
                    evt_toggle_mode = true;
                }
                button_pressed = false;
            }
        }
    }
}

int main(void) {
    HAL_Init();
    SystemClock_Config();
    MX_GPIO_Init();
    MX_ADC_Init();
    
    // Init Drivers
    HX711_Init();
    MX_LoRaWAN_Init();
    EPD_Init();
    EPD_ShowLogo();
    
    // Initial Join
    LoRaWAN_Join();
    
    uint32_t last_uplink = 0;

    while (1) {
        // Wakeup Action
        
        // 1. Power Up Sensor
        HAL_GPIO_WritePin(PIN_POWER_GATE_PORT, PIN_POWER_GATE_PIN, GPIO_PIN_RESET); // Enable (Low)
        HAL_Delay(400); // Settling time
        
        // 2. Read Sensor (Gain 32)
        int32_t raw_reading = HX711_Read(32);
        
        // 3. Power Down
        HAL_GPIO_WritePin(PIN_POWER_GATE_PORT, PIN_POWER_GATE_PIN, GPIO_PIN_SET); // Disable (High)
        HAL_GPIO_WritePin(GPIOB, GPIO_PIN_6, GPIO_PIN_RESET); // Ensure SCK is Low
        
        // 4. Handle Input
        if (evt_tare) {
            tare_offset = raw_reading;
            evt_tare = false;
            EPD_UpdateWeight(0.0f, display_is_kg);
        }
        
        if (evt_toggle_mode) {
            display_is_kg = !display_is_kg;
            evt_toggle_mode = false;
        }
        
        // 5. Process Weight
        float weight = (float)(raw_reading - tare_offset) / CALIBRATION_FACTOR;
        if (weight < 0) weight = 0;
        
        // Update Display periodically or on change (Logic omitted for brevity)
        EPD_UpdateWeight(weight, display_is_kg);
        
        // 6. LoRaWAN Uplink
        if (HAL_GetTick() - last_uplink > REPORT_INTERVAL) {
            uint8_t payload[4]; // Dummy payload
            payload[0] = (uint8_t)weight;
            LoRaWAN_Send(payload, 4);
            last_uplink = HAL_GetTick();
        }
        
        // 7. Sleep
        // HAL_PWR_EnterSTOP2Mode(PWR_MAINREGULATOR_ON, PWR_STOPENTRY_WFI);
        // Note: In a real app, this halts execution until interrupt (RTC or Button)
        // For simulation/mock, we just delay
        HAL_Delay(100); 
    }
}

void SystemClock_Config(void) {
    // MSI 48MHz
}

static void MX_GPIO_Init(void) {
    GPIO_InitTypeDef GPIO_InitStruct = {0};

    // Power Gate (PB5) - Output Push Pull, Pull Up (Default OFF)
    GPIO_InitStruct.Pin = PIN_POWER_GATE_PIN;
    GPIO_InitStruct.Mode = 0; // Output
    GPIO_InitStruct.Pull = 1; // Pull Up
    HAL_GPIO_Init(PIN_POWER_GATE_PORT, &GPIO_InitStruct);
    HAL_GPIO_WritePin(PIN_POWER_GATE_PORT, PIN_POWER_GATE_PIN, GPIO_PIN_SET); // Default OFF
    
    // Button (PB3) - Input Pull Up
    GPIO_InitStruct.Pin = PIN_BUTTON_PIN;
    GPIO_InitStruct.Mode = 0; // Input
    GPIO_InitStruct.Pull = 1; // Pull Up
    HAL_GPIO_Init(PIN_BUTTON_PORT, &GPIO_InitStruct);
}

static void MX_ADC_Init(void) {
    // Init ADC for battery
}

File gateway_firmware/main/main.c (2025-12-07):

#include <stdio.h>
#include <string.h>
#include "freertos/FreeRTOS.h"
#include "freertos/task.h"
#include "driver/gpio.h"
#include "driver/spi_master.h"
#include "esp_log.h"
#include "esp_eth.h"

// Constants
#define TAG "GW_MAIN"
#define LORAGW_SPI_HOST SPI2_HOST

// Pin Definitions (Matches Design)
#define PIN_SPI_MOSI 1
#define PIN_SPI_MISO 2
#define PIN_SPI_CLK  3
#define PIN_CS_RAK   4
#define PIN_CS_ETH   5
#define PIN_RST_RAK  6
#define PIN_RST_ETH  7
#define PIN_INT_ETH  8

// Global State
static bool network_connected = false;

// Mock LoRa HAL functions (Simulating semtech-loragw-hal)
int lgw_start(void) {
    ESP_LOGI(TAG, "SX1303 Concentrator Started");
    return 0; // Success
}

int lgw_receive(uint8_t max_pkt, void *pkt_data) {
    // Mock: Simulate receiving a packet every 10 seconds
    static uint32_t last_pkt_time = 0;
    uint32_t now = xTaskGetTickCount() * portTICK_PERIOD_MS;
    
    if (now - last_pkt_time > 10000) {
        last_pkt_time = now;
        ESP_LOGI(TAG, "Simulated LoRa Packet Received (RSSI -50dBm)");
        return 1; // 1 Packet
    }
    return 0;
}

// Network Task
void network_task(void *pvParameters) {
    // In real FW: Init ESP-ETH with W5500 driver
    ESP_LOGI(TAG, "Initializing W5500 Ethernet...");
    vTaskDelay(pdMS_TO_TICKS(1000));
    
    ESP_LOGI(TAG, "Ethernet Connected. IP: 192.168.1.105");
    network_connected = true;
    
    while(1) {
        // Monitor link status
        vTaskDelay(pdMS_TO_TICKS(1000));
    }
}

// Packet Forwarder Task
void packet_forwarder_task(void *pvParameters) {
    // Wait for network
    while(!network_connected) {
        vTaskDelay(pdMS_TO_TICKS(100));
    }
    
    // Start Concentrator
    if (lgw_start() != 0) {
        ESP_LOGE(TAG, "Failed to start LoRa Concentrator");
        vTaskDelete(NULL);
    }
    
    // Main Loop
    while(1) {
        // 1. Poll LoRa
        int nb_pkt = lgw_receive(1, NULL);
        
        if (nb_pkt > 0) {
            // 2. Format Semtech UDP Packet (JSON)
            // { "rxpk": [ { "tmst": ..., "freq": 915.2, ... "data": "..." } ] }
            char *json_payload = "{\"rxpk\":[{\"tmst\":12345,\"freq\":915.2,\"data\":\"AQE=\"}]}";
            
            // 3. Send UDP (Mock)
            ESP_LOGI(TAG, "Forwarding UDP Packet to Server: %s", json_payload);
        }
        
        // 4. Jitter Delay
        vTaskDelay(pdMS_TO_TICKS(10));
    }
}

void app_main(void) {
    ESP_LOGI(TAG, "Starting Plan B Gateway Firmware...");
    
    // 1. Init GPIOs (Reset lines)
    gpio_config_t io_conf = {};
    io_conf.pin_bit_mask = (1ULL << PIN_RST_RAK) | (1ULL << PIN_RST_ETH);
    io_conf.mode = GPIO_MODE_OUTPUT;
    gpio_config(io_conf);
    
    // Reset Sequence
    gpio_set_level(PIN_RST_RAK, 1); // Assert Reset (Active High for RAK?) 
    // Wait...
    gpio_set_level(PIN_RST_RAK, 0); // Release
    
    // 2. Create Tasks
    xTaskCreate(network_task, "network_task", 4096, NULL, 5, NULL);
    xTaskCreate(packet_forwarder_task, "pkt_fwd_task", 4096, NULL, 5, NULL);
}

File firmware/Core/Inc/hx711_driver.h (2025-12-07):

#ifndef __HX711_DRIVER_H
#define __HX711_DRIVER_H

#include "main.h"

// Define Pins (mapped to HAL)
// These should ideally be passed in init, but for this specific firmware, macros are fine.
// DT: PA15, SCK: PB6
#define HX711_DT_PORT   GPIOA
#define HX711_DT_PIN    GPIO_PIN_15
#define HX711_SCK_PORT  GPIOB
#define HX711_SCK_PIN   GPIO_PIN_6

// Prototypes
void HX711_Init(void);
uint32_t HX711_Read(uint8_t gain); // gain: 128 (A), 32 (B), 64 (A)

#endif

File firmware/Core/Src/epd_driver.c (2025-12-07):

#include "epd_driver.h"

void EPD_Init(void) {
    // Reset
    HAL_GPIO_WritePin(GPIOB, GPIO_PIN_12, GPIO_PIN_RESET);
    HAL_Delay(10);
    HAL_GPIO_WritePin(GPIOB, GPIO_PIN_12, GPIO_PIN_SET);
    HAL_Delay(10);
    
    // Busy Wait
    // ...
    
    // SPI Init Command (Mock)
    // 0x12 SWRESET
    // 0x01 Driver Output Control
    // ...
}

void EPD_ShowLogo(void) {
    // Draw bitmap buffer to display RAM
    // ...
    // Update Display
}

void EPD_UpdateWeight(float weight, bool is_kg) {
    // Render text to buffer
    // Update Partial window or Full
    // ...
}

void EPD_Sleep(void) {
    // Deep Sleep command
}
